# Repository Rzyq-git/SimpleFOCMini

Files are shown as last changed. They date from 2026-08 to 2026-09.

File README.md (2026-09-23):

# SimpleFOCMini v2.3
This is a miniature BLDC driver board based on the DRV8316 driver intended to be used with the SimpleFOC library.

📢 NEW: This board is now available in our collaboration with **Makerfabs**: [See more on makerfabs.com](https://www.makerfabs.com/simplefocmini.html)

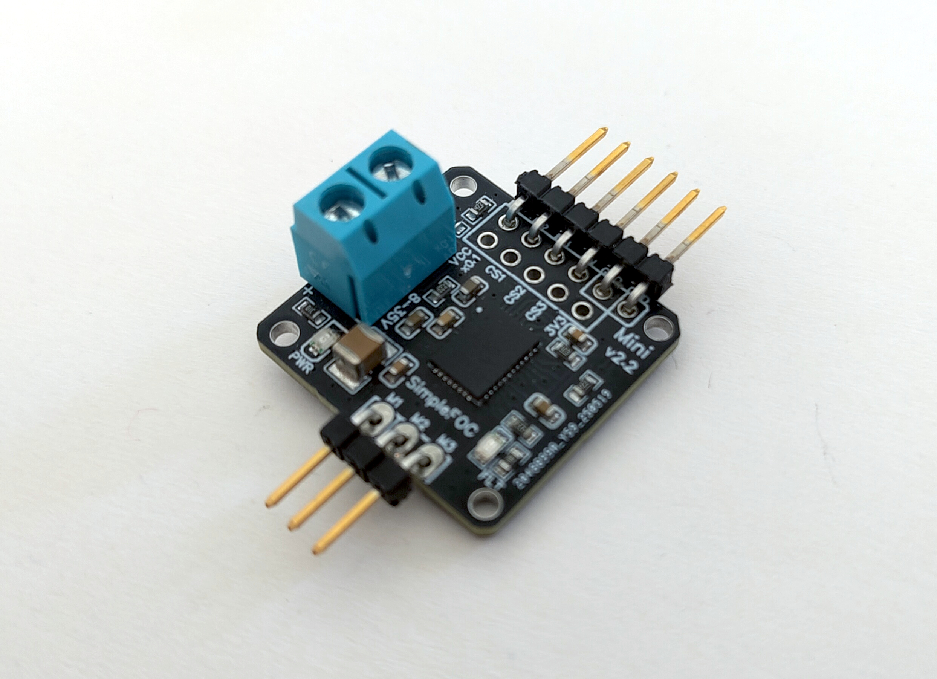
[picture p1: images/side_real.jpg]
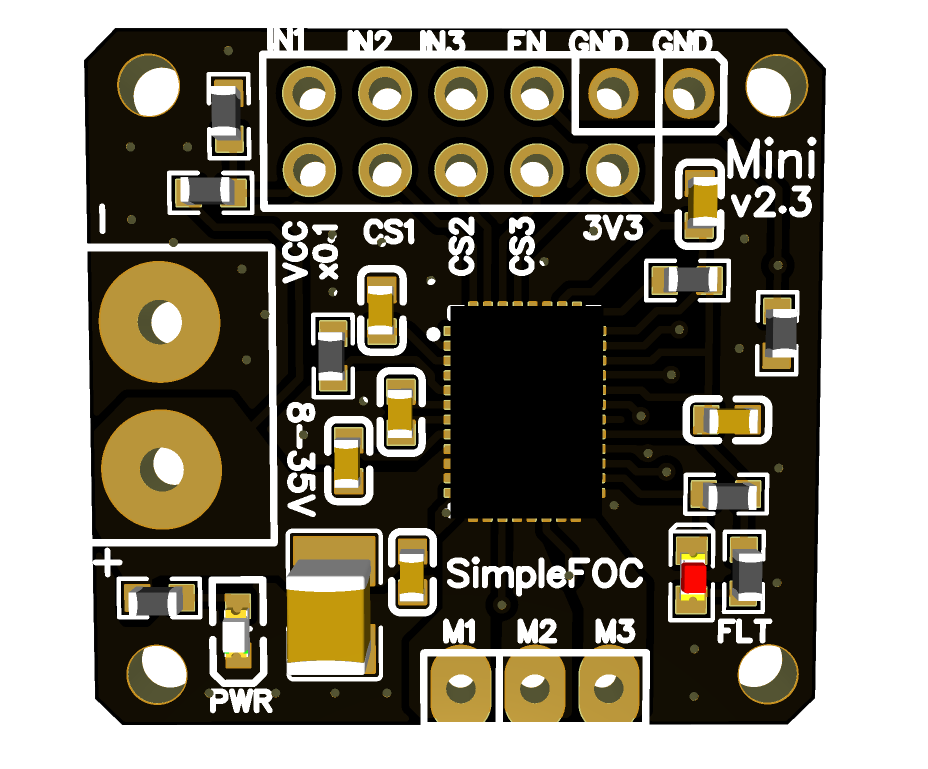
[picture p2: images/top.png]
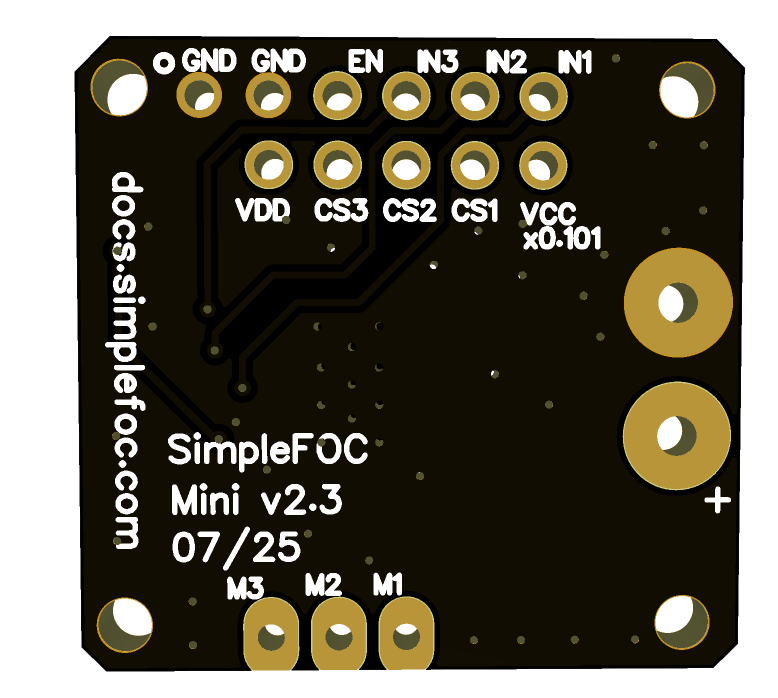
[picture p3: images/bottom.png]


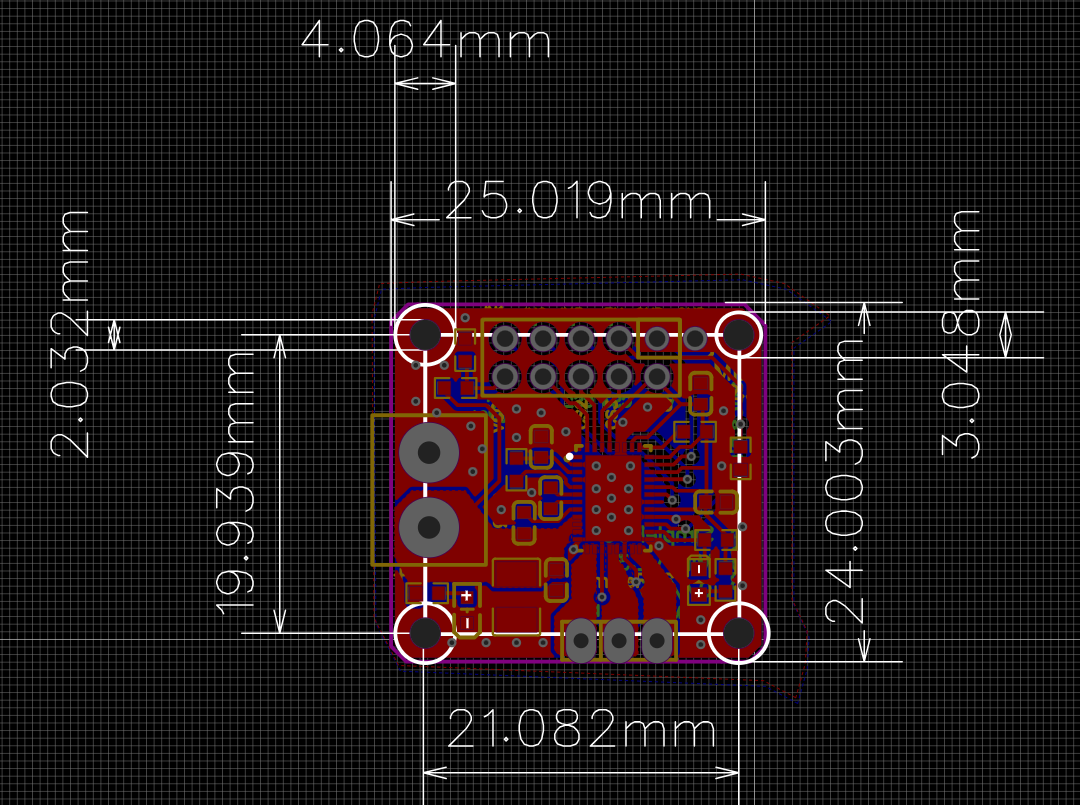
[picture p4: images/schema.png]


## Features
- DRV8316 based - [datasheet](https://www.ti.com/lit/ds/symlink/drv8316.pdf?ts=1786687969913)
  - Power supply: 5-35V
  - Max current: 8A  
  - Onboard 3.3V LDO (20mA)
  - 3-PWM mode
- Sensing
  - 3x Low-side current sensing (150mV/A)
  - Power supply voltage sensing (Scale 0.1V/V)
- Pinout
  - Pins can be stacked on a protoboard 
  - 3xPWM + ENABLE can be stacked on an Arduino UNO style header
  - Compatible pinout with the v1.1 version of the board
- Small size 24x25 mm
- Fully compatible with the *Simple**FOC**library*
- Fully open-source: [EasyEDA link](https://oshwlab.com/the.skuric/simplefocmini_copy_copy)
- Low-cost:
  - JLCPCB production cost ~5€
  - Available through [Makerfabs.com](https://www.makerfabs.com/simplefocmini.html)

## New features in v2+
- Complete redesign from v1.1
- More powerful DRV8316 driver with higher current capability
- Integrated low-side current sensing for all 3 phases
- Integrated voltage sensing for the power supply

## Compatibility with v1.1
- This version is fully compatible with the code written for the v1. 
- The PWM and ENABLE pinout is the same as v1.1.
- The board is slightly bigger (24x25mm vs 20x26mm).

## ⚠️ BEWARE : Low-side current sensing
Not all MCU architectures support low-side current sensing with SimpleFOC, so please check the [SimpleFOC documentation](https://docs.simplefoc.com/microcontrollers) for more information.

## Getting started with SimpleFOCMini

See the documentation in the [SimpleFOC documentation](https://docs.simplefoc.com/simplefocmini) page. 
- The docs explain how to start with the SimpleFOCMini board and how to use it with the SimpleFOC library. 
- They also describe how you can order it directly from the JLCPCB.

## Release log

Release | Date | Description
--- | --- | ---
v2.3 | 2025-07 | Added a new version with a smaller size and improved layout, and voltage sensing for the power supply.
v2.0 | 2025-01 | Complete redesign of the board with DRV8316
v1.1 | 2024-04 | A quick iteration with a few changes: <p> 1. Aligned motor output header with the input header so that it can be stacked in the protoboard<br>2. Input header updated to be easier to use with arduino UNO, nucleos, but also with qtpy...<br> - Changed the order of the IN1,IN2,IN3 and EN: <br>    - Added an additional GND pin <br>
v1.0 | 2022-04 | Initial release

## Size comparison

mini v1| mini v2
--- | ---
20x26 mm | 24x25 mm

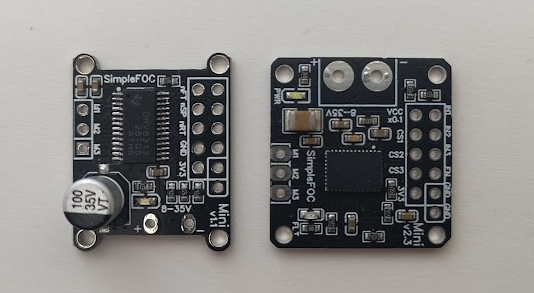
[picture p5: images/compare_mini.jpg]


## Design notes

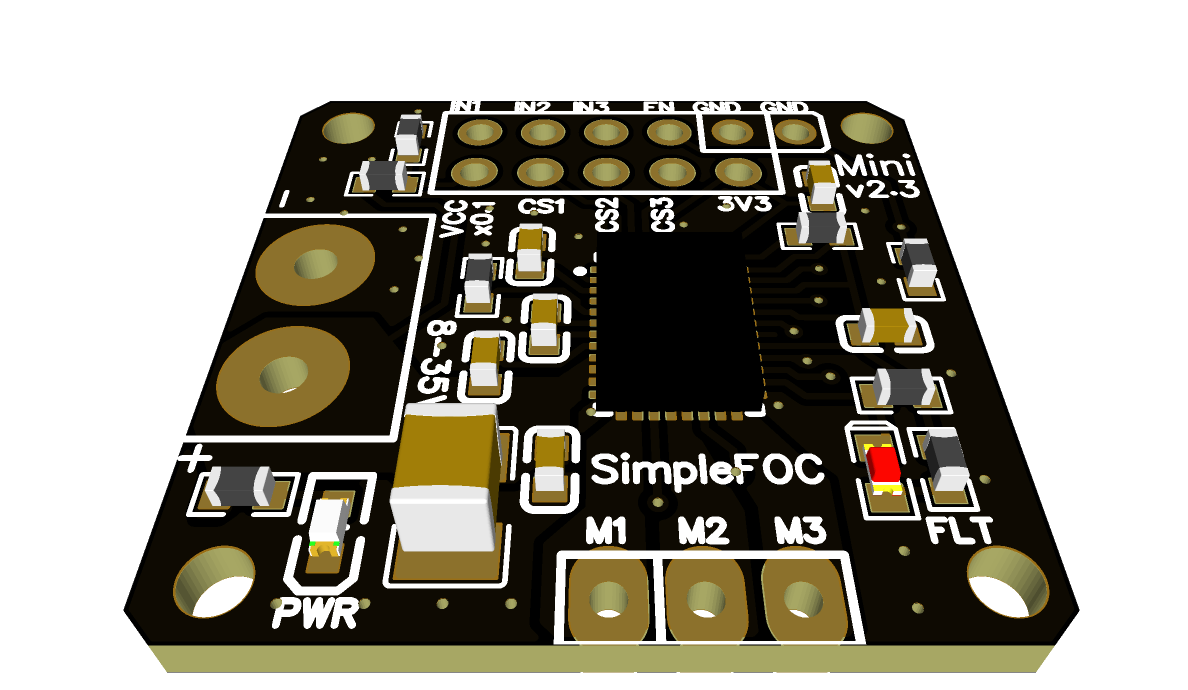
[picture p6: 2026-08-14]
images/side.png

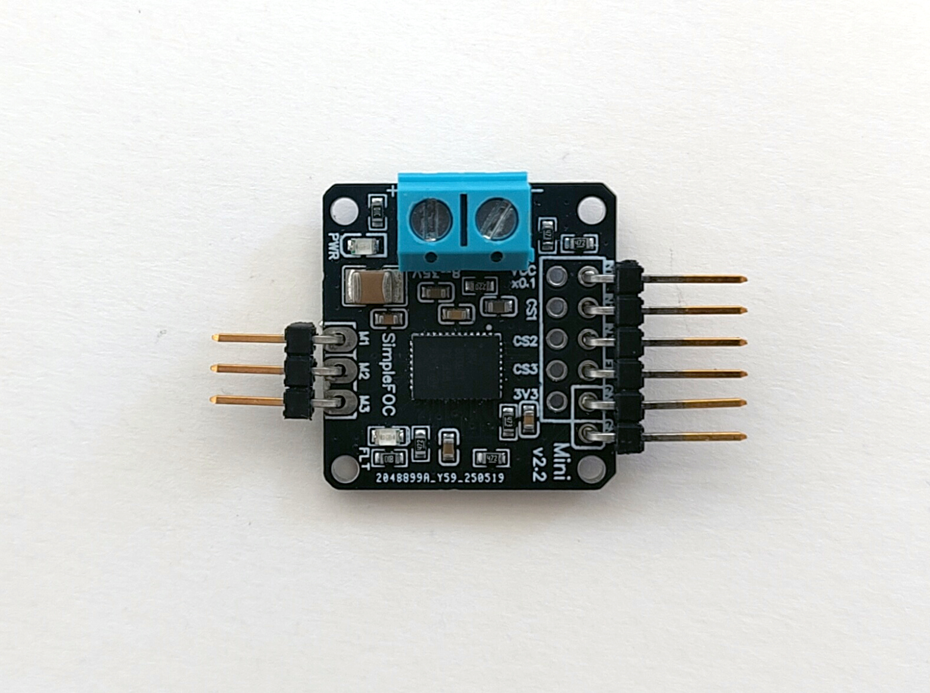
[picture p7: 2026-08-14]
images/top_real.jpg

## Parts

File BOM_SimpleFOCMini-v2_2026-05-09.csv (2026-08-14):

ID | Name | Designator | Footprint | Quantity | Manufacturer Part | Manufacturer | Supplier | Supplier Part
1 | LED-0603 | D2 | LED0603 | 1 | KT-0603R | Hubei KENTO Elec | LCSC | C2286
2 | 10kΩ | R5 | R0603 | 1 | 0603WAF1002T5E | UNI-ROYAL(Uniroyal Elec) | LCSC | C25804
3 | 47k | R_DV1,R_MODE | R0603 | 2 | 0603WAF4702T5E | UniOhm | LCSC | C25819
4 | 1kΩ | R3 | R0603 | 1 | 0603WAF1001T5E | UNI-ROYAL(Uniroyal Elec) | LCSC | C21190
5 | 10uF | C_VM2 | C1210 | 1 | CL32B106KBJNFNE | SAMSUNG(三星) | LCSC | C18739
6 | 1uF | C_AVDD,C_CP | C0603 | 2 | CL10A105KB8NNNC | SAMSUNG | LCSC | C15849
7 | 47nF | C_FLY | C0603 | 1 | CL10B473KB8NNNC | SAMSUNG | LCSC | C1622
8 | 100nF | C_VM1,C_VREF | C0603 | 2 | CC0603KRX7R9BB104 | SAMSUNG | LCSC | C14663
9 | 22uF | C_AVDD1 | C0603 | 1 | CL10A226MQ8NRNC | SAMSUNG | LCSC | C59461
10 | 22Ω | R_BK | R0603 | 1 | 0603WAF220JT5E | UniOhm | LCSC | C23345
11 | 4.7kΩ | R_DRVOFF,R_FLT, R_DV2 | R0603 | 3 | 0603WAF4701T5E | UniOhm | LCSC | C23162
12 | DRV8316CTRGFR | U2 | VQFN-40_L7.0-W5.0-P0.50-TL-EP5.7 | 1 | DRV8316CTRGFR | TI(德州仪器) | LCSC | C6602057
13 | led red 0603 | LED1 | LED0603-R | 1 | KT-0603W | Hubei KENTO Elec | LCSC | C2290

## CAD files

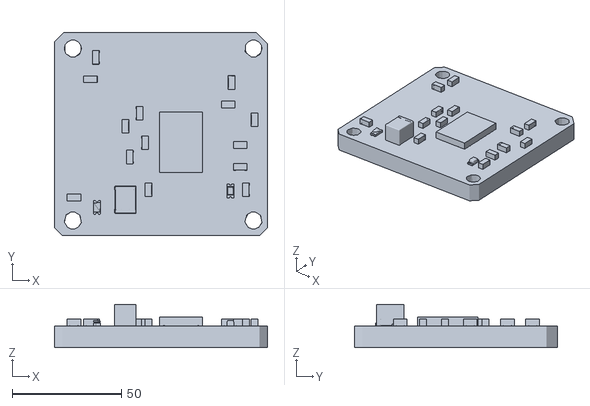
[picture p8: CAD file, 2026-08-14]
3D model/OBJ_simplefocmini_v2.obj
97.3 x 92.8 x 19.8

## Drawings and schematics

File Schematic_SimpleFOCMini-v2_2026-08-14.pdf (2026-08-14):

# OUTC 20 OUTC 19 OUTB 17 OUTB 16 OUTA 14 OUTA 13

## INLC 32 INLB 30 INLA 28 INHC 31 INHB 29 INHA 27

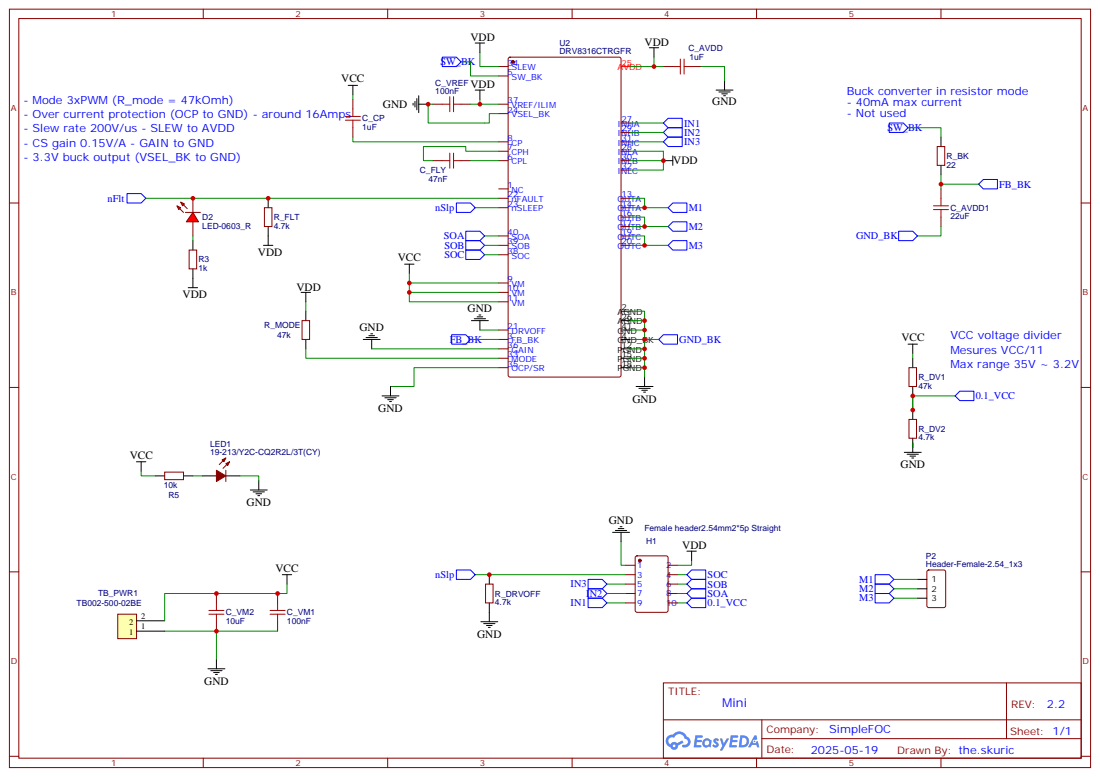
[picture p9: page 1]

Buck converter in resistor mode
- 40mA max current
- Not used

- Mode 3xPWM (R_mode = 47kOmh)
- Over current protection (OCP to GND) - around 16Amps
- Slew rate 200V/us - SLEW to AVDD
- CS gain 0.15V/A - GAIN to GND
- 3.3V buck output (VSEL_BK to GND)

Drawn By: the.skuric
